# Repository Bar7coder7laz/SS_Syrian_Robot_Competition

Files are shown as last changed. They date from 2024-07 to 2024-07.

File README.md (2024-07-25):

Scud Storm Team Report for WRO Future Engineers Category (2024)
====
This repository represents the Scud Storm team's work for the WRO Future Engineers Category competition in 2024. It includes all the necessary documentation, code, models, and other materials used in the design, construction, and programming of our self-driving robot. Our focus has been on creating a robust and efficient vehicle capable of navigating a track with obstacles, adhering to competition rules, and demonstrating advanced engineering skills.

**Important Note:** If the GitHub repository is accessed from a restricted area, a VPN must be used for the repo to look good and display all content properly.

# Content

* `t-photos` contains 2 photos of the team (an official one and one funny photo with all team members)
* `v-photos` contains 6 photos of the vehicle (from every side, from top and bottom)
* `video` contains the video.md file with the link to a video where driving demonstration exists
* `schemes` contains one pdf for all the electromechanical components illustrating all the elements (electronic components and motors) used in the vehicle and how they connect to each other.
* `src` contains code of control software for all components which were programmed to participate in the competition
* `models` contains all the files used by 3D printers, laser cutting machines and CNC machines to produce the vehicle elements.
* `other` contains images thar used in this repository.

# Robot Mechanism

In self-driving cars, the most important aspect is their mechanical mechanisms, which ensure smooth and safe operation. Our design incorporates differential gears for the Rear-Wheel Drive (RWD) system, providing balance and control during turns. For steering, we utilize a Direct-Acting Steering mechanism, which offers precise control and reliability.

## Differential Gears

Differential gears play a crucial role in automotive engineering. They allow the wheels on a vehicle to rotate at different speeds, particularly when the car is turning. This functionality is vital because the inner wheels travel a shorter distance than the outer wheels during a turn.

### Types of Differentials

1. **Open Differential**: is the most common type, found in many non-performance vehicles. It is simple and cost-effective but can transfer torque to a wheel without traction, causing it to spin uselessly.

   <p align="center">
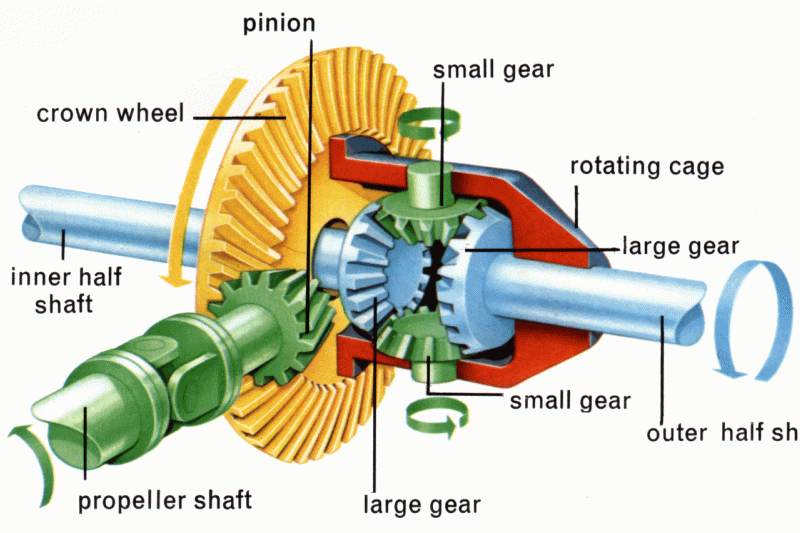
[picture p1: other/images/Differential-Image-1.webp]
     
   </p>

2. **Locking Differential**: Often used in off-road vehicles, this type can lock the wheels to spin at the same speed, providing better traction on uneven surfaces.

   <p align="center">
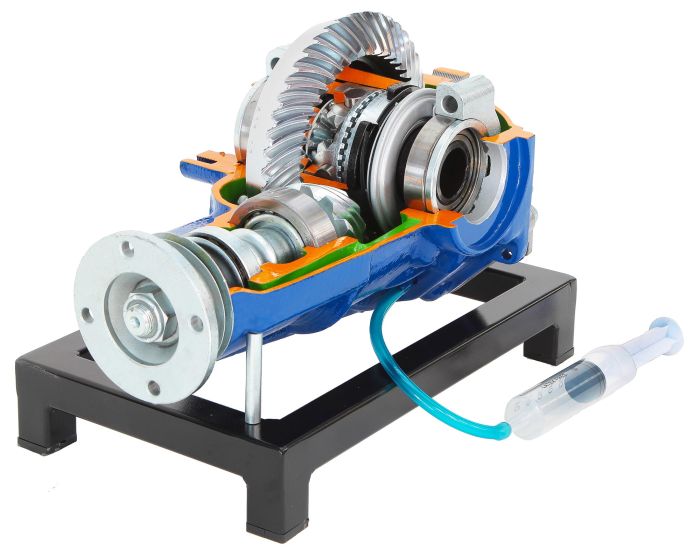
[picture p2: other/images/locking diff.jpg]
     
   </p>

3. **Limited-Slip Differential (LSD)**: Combines features of both open and locking differentials, allowing wheels to spin at different speeds but can transfer more torque to the wheel with better traction.

   <p align="center">
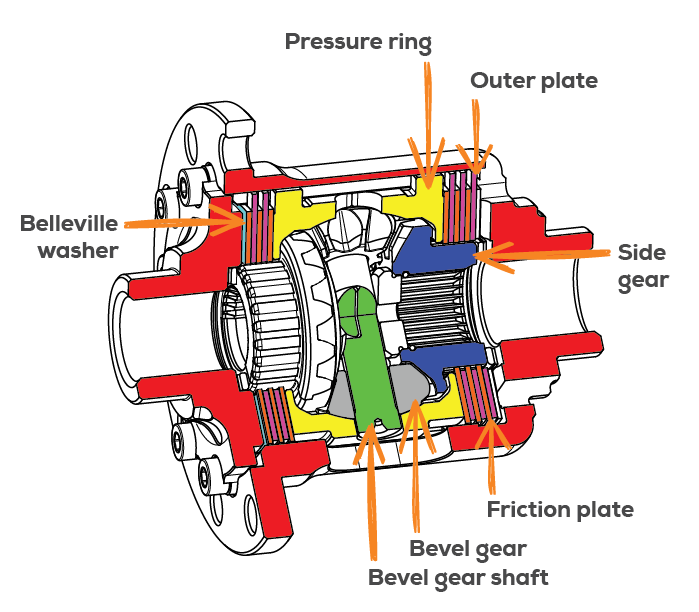
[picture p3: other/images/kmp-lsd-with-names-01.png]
     
   </p>

### Benefits of Differential Gears

- **Improved Handling**: Differentials enhance vehicle handling, especially around corners, by allowing wheels to rotate at appropriate speeds.
- **Increased Traction**: Locking and limited-slip differentials provide better traction on slippery or uneven surfaces.
- **Enhanced Stability**: They improve stability by distributing power evenly to the wheels, preventing loss of control.

## Direct-Acting Steering

Direct-Acting Steering mechanisms provide precise and responsive control, essential for the safety and efficiency of self-driving cars. This system translates the driver's or automated system's input directly into wheel movement without the delay and complexity of traditional steering systems.

### Advantages of Direct-Acting Steering

- **Enhanced Precision**: Direct control over the wheels' movement allows for more accurate and reliable steering.
- **Increased Safety**: By reducing the potential for mechanical failure, direct-acting systems improve the vehicle's overall safety.
- **Better Responsiveness**: The immediate translation of steering input to wheel action ensures a quicker response to driving conditions.

## Fusion Between Differential Gears and Direct-acting Steering Mechanisms in Our Robot

### Differential Gears Using Lego Parts
In our robot, we used differential gears, as shown in the following photo:

<p align="center">
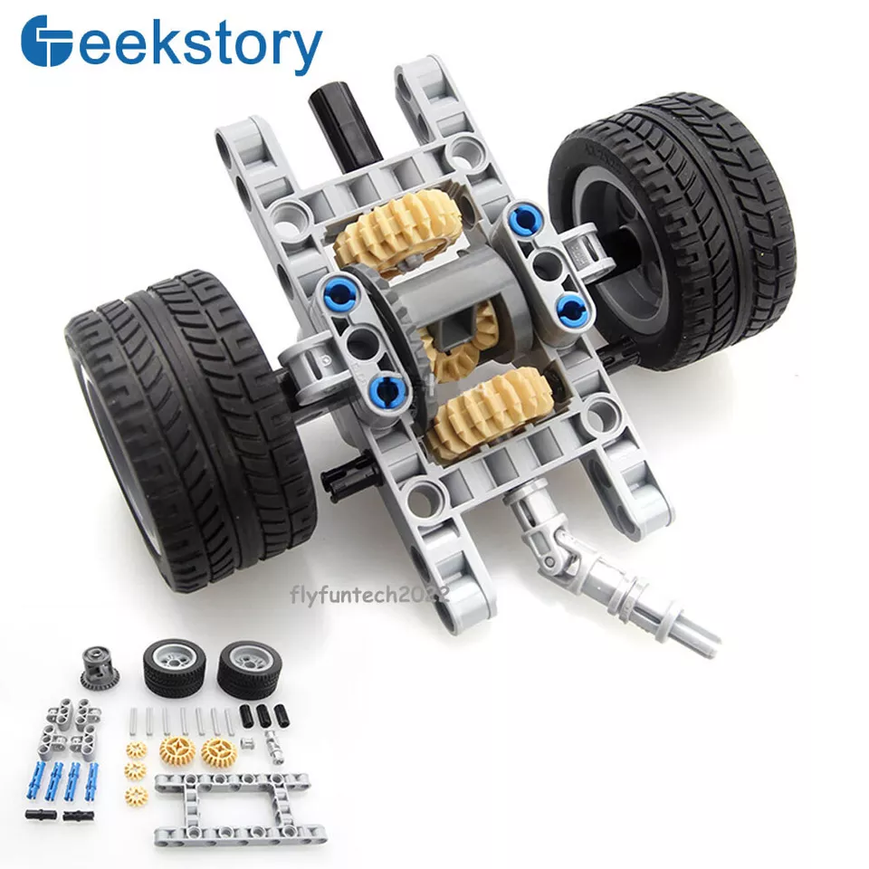
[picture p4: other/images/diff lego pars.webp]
  
</p>

### Direct-Acting Steering depending on Picar-X Kit
The steps of assembling the steering mechanism are shown below step-by-step:

<p align="center">
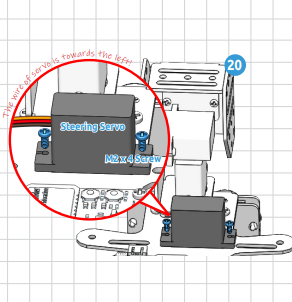
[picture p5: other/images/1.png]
  
</p>

<p align="center">
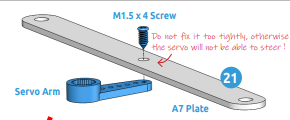
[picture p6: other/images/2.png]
  
</p>

<p align="center">
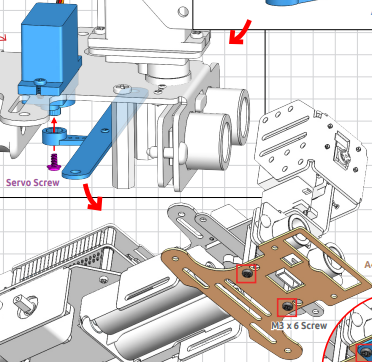
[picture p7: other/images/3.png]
  
</p>

<p align="center">
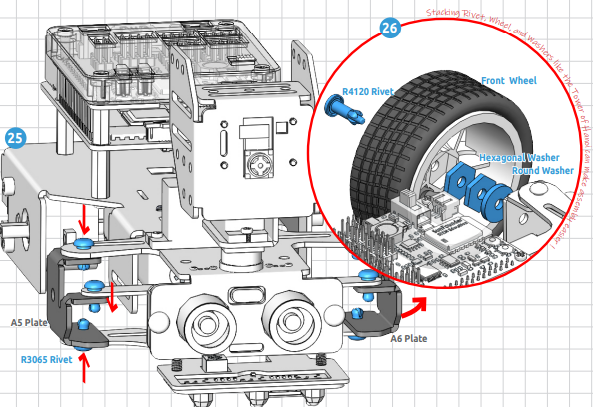
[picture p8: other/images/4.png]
  
</p>

Incorporating differential gears and direct-acting steering mechanisms in self-driving cars is essential for ensuring smooth turns, improved traction, precise control, and overall vehicle stability. Understanding these components helps us appreciate the technology that contributes to safer and more efficient driving experiences.

## Vehicle Main Body

The vehicle's main body is based on the Picar-x kit. The building instructions are available via the [link](https://github.com/sunfounder/sf-pdf/raw/master/assembly_file/a0000710-picar-x.pdf) with some vital modifications and crucial restructuring in order to be able to meet the competition requirements:

The robot Rear Wheel Drive (RWD) is the most important factor in any car whether it is a real car or a self-driving car. The Picar-x kit had two DC motors each one is responsible for one wheel. However, we are required to use one DC so we crafted a new design for the RWD. In this design, the transmission of motion is achieved through the implementation of differential gears using LEGO parts. The Importance of Differential Gears lies in that it enables the rear wheels to spin simultaneously at various speeds while preserving power distribution. When the robot is turning or there is a discrepancy in traction between the two wheels, the differential gear's main job is to allow the wheels on the same axle to rotate at different rates. It permits the wheels to spin at different speeds while distributing torque from the DC Motor to them. In order for the rear wheels to be compatible with the Lego differential gears, they were also replaced with Lego wheels. It's crucial to note that we utilized the identical Direct Acting Steering mechanism as the kit described above; but, because of their low friction characteristic, the front wheels had to be replaced due to the fact that the robot needs more force to steer at the right value.

Due to space constraints, we also added two extra plexi plates to the primary chassis of the robot( the primary chassis can only hold a place for the LiPo battery that we have). The first plexi was required for eight ultrasonic sensors (three on each side, one in front, and one in the back, and one in the middle with a drift angle of 35 degrees),  and a place for our main microcontroller is Atmega which is mounted on Arduino Mega 2560 board.Moreover, this plexi also contains a small fan for the RaspberryPi 4B, and a BTS7960 to control the DC motor. The RaspberryPi 4B, our robot's primary microprocessor, is located in the second plexi. On the other hand, the RaspberryPi is linked to a camera module that is located on two SG90 Servos, one of which moves it horizontally and the other vertically. Lastly, MPU_6050 is situated both above and in the middle of the robot with regard to the x and y axes. For more accurate measurements, we positioned the mpu precisely in the center of the robot using Lego parts.

### Picar-X Robot _VS_ Scud Storm Robot _(Our Robot)_ 
The following photos show a comparasion between our robot and the Picar-X Robot. This comparasion is to show how much effort did we put to the design to satisfy our algorithm requirments and the competition requirments:

<p align="center">
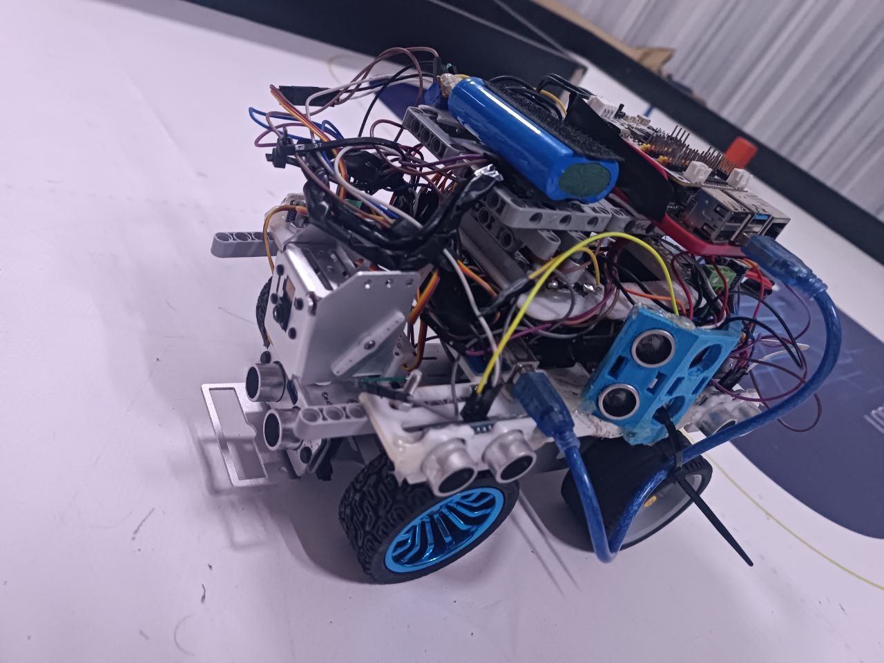
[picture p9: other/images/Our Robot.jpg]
Robot position before turn
  
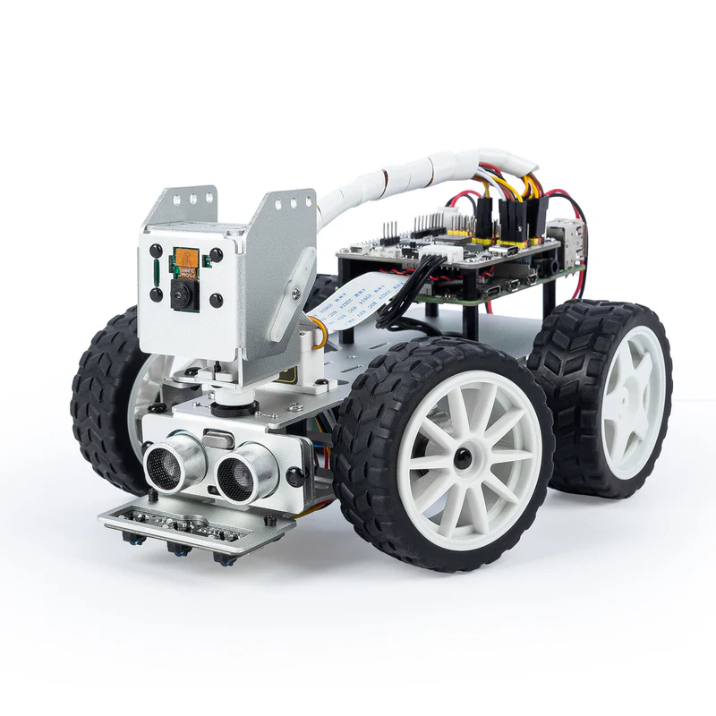
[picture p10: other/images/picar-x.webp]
  
</p>

## Mobility Management

### DC Motor

In general, the motors used in small self-driving cars are expected to possess several key attributes including light weight, compactness, and high efficiency. These characteristics are necessary to ensure that the motor can operate for extended periods of time while utilizing a limited power source. A motor that is relatively low-speed could be suitable for a small self-driving car as it can provide adequate torque to drive the vehicle while also being lightweight and compact. However, the selection of a motor for a self-driving car is influenced by a variety of factors such as the vehicle's size and weight, the desired speed and torque output, and the power requirements of the electronic components. Other considerations include the availability and cost of replacement parts as well as the level of expertise needed for installation and maintenance. After taking into account all of these factors the DC JGA25- 245 RPM motor was chosen because it met the desired specifications. It provides the following features: 

| Speed (r/min) | Current (Amp) | Torque (Kg.cm) | Power (Watt) |
|---|---|---|---|
| 133 | 0.5 | 0.75 | 1.1 |
| 245 | 0.65 | 1.4 | 2.4 |

### Motor Control Setup

To control the DC motor we used BTS 7960 driver circuit and the Arduino Mega board. Then we followed these steps:

1. We connected the BTS 7960 driver to the Arduino Mega. The BTS 7960 driver has six input pins which are used to control the motor. However, we only needed 4 pins to control our motor reliably. These pins are connected to the appropriate pins on the Arduino Mega. The connections are:
   - L_EN and R_EN pins are connected to digital output pins on the Arduino Mega.
   - L_PWM and R_PWM are connected to PWM output pin on the Arduino Mega.
2. Then we connected the DC motor to the BTS 7960 driver: The DC motor is connected to the output terminals of the BTS 7960 driver. The polarity of these connections determines the direction of the motor rotation.
3. Lastly, we connected the driver to an external 12V power supply.

### Servo Motor

Our choice of a SG90 Micro Digital 9G Servo (SunFounder Servo) motor for a small self-driving car depended on several factors which are presented below:

- **Compact size:** The SunFounder Servo motor is a small and lightweight motor (10± 0.5g) which makes it ideal for use in small self-driving cars where space is limited.
- **High torque:** Despite its small size, the SunFounder Servo motor can provide a relatively Stall Torque (1.4 kg/cm (4.8V) 1.6 kg/cm (6V)) which is essential for steering the car accurately and precisely.
- **Wide operating range:** The SunFounder Servo motor has a wide operating range of 0-180 degrees with a mechanical limit angle is 360 degrees which makes it versatile and suitable for a variety of steering applications.
- **Low power consumption:** The motor has a relatively low power consumption as follows:
  - Standby Current: ≤4 mA
  - Consumption Current (at 4.8V No Load): ≦50mA
  - Consumption Current (at 6 V no load): ≦60mA
  - Stall Current (at locked 4.8V): ≦550mA
  - Stall Current (at locked 6V): ≦650mA
- **High speed:** The motor has a suitable speed for the steering task (No Load Speed: 4.8V ≦0.14sec/60°; 6V ≦0.12sec/60°).

## Robot Design

Designing a robot for the Future Engineers WRO competition requires careful planning and consideration of several factors. For that we followed the following steps:

### Understanding the Competition Requirements

The first step is to thoroughly read and understand the competition rules and requirements. This helped us determine the specific tasks that the robot needs to perform and the constraints that need to be considered such as the weight and the dimensions of the robot.

### Defining the Robot's Objectives

Based on the competition requirements we determined the objectives of the robot such as the tasks it needs to perform the environment it will operate in and the constraints it needs to adhere to.

### Designing the Robot's Mechanical System
#### RWD Mechannism

It was previousely explained in details in this repository.

#### Steering Mechanism

Once the objectives are defined design the mechanical system of the robot including the wheels motors and any other mechanical components needed to achieve the objectives. As a steering mechanism, we chose the Direct-Acting steering mechanism which is a popular choice for small self-driving cars because it provides accurate and precise control over steering while also being relatively simple to implement. This mechanism uses a linkage system to allow the front wheels to turn at the same angles which is better when dealing with small self-driving cars than Ackermann steering for example. This design allows the car to have a small turning radius which is important for navigating tight spaces and making sharp turns. Additionally, it provides a stable and predictable steering response which is crucial for self-driving cars that need to maintain precise control over their movements.

### Choosing the Electronic Components

The selection process for the electronic components that will govern the robot's movements and behaviors has been conducted meticulously. These components include the microcontroller- an Arduino Mega board, and the microprocessor- a RaspberryPi 4B. Sensory devices have also been chosen encompassing Ultrasonic sensors, mpu6050 (gyroscope and acceleration sensor), and a RaspberryPi Camera 1.3 module (5 MegaPixels) which will provide the robot with the ability to perceive its environment. Actuators including a DC Motor and a Servo Motor have been chosen to facilitate the physical actions of the robot. The power supply will be ensured by one Li-poly RC 12 V and two 18650 li-ion (3.7 V) batteries. Additional electrical components such as the driver circuit and two step down voltage regulators (Lm2596) have also been selected to augment the robot's functionality. These components collectively will provide the necessary control over the robot's movements and actions.

## Power and Sense Management

### Power Supply

In our design, we utilized two 18650 li-ion (3.7 V) batteries to provide power for the RaspberryPi (since we have serial communication, RaspberryPi supplies Arduino). Additionally, the Li-poly RC 12 V is responsible to power all the other electronic components.

### Sensors

In addition to using a gyroscope, acceleration sensors (mpu 6050), and a camera to detect pillars, we integrated eight ultrasonic sensors (HC-SR04), three of which were placed on each side of the robot, one on the front side, and one on the left back side. Two of the sensors on each side have a unique feature in that two of them are parallel to the walls, but the middle one has a drifting angle of 35 degrees, a number that was carefully studied because it adds a great deal of flexibility to the obstacles management algorithm.

## Open Challenge Strategy

### Ultrasonic Sensors Reading

We created a newping array that contains all the sensors. It contains each sensor's trigger pin echo pin and max distance to ping. We also used a function that calculates the distance measured by an ultrasonic sensor with a specific id. The function uses a median filter to obtain a more accurate and stable distance measurement.

### Keeping the Robot Straight in the First Straightforward Section

We used a PD controlling algorithm that depends on the value of the tilt angle measured by the gyroscope sensor to calculate the corrected angle. This algorithm controls the robot in a way that makes the tilt angle measured by the gyroscope equal to a reference angle. And any deviating from this reference will be considered an error and will be corrected by the algorithm. We used this algorithm to control the robot movement in the first straightforward section before identifying the movement direction. The algorithm works as follows:

#### Identifying the Reference Angle

The reference angle is the angle measured by the gyroscope at the beginning of the round. It is important to consider that the robot may not be completely straight at the beginning of the round so the reference angle is corrected by subtracting the tilt angle of the robot that is calculated depending on ultrasonic sensors’ readings.

#### Calculating Angle Error

The angle error is the difference between the angle measured by the gyroscope during the movement and the reference angle.

<p align="center">
  
</p>

#### Calculating the PD Output

<p align="center">
  
</p>

Where:
- out is the output correction of the algorithm.
- angError_t is the angle error calculated at the time t.
- angError_{t-1} is the angle error calculated at the time t-1.
- timeDifference is the time difference between the two readings of the angle.
- k_p is the proportional constant.
- k_d is the differential constant.

#### Calculating the Corrected Angle

The corrected angle is the angle that would be set to the servo motor to correct the robot movement. It is calculated with the following formula:

<p align="center">
  
</p>

Where:
- servoAng is the angle that would be set to the servo motor to keep the robot straight.

### Detecting the First Turn and the Direction of Movement

If one of the left ultrasonics detects a distance greater than a specific threshold, then the direction of movement is counterclockwise. On the other hand, if one of the right ultrasonics detects a distance greater than the threshold, the direction of movement is clockwise. To make the code more dynamic we created two arrays called arr1 and arr2. Arr1 stores the IDs of the ultrasonic sensors that would be used to detect the wall, whereas arr2 stores the IDs of the ultrasonic sensors that would be used to detect a turn. The values of these two arrays are identified in the first turn.

### Keeping the Robot Straight After Identifying the Direction of Movement

After identifying the direction of movement the robot will be kept straight depending on wall detection algorithm that detects the outer wall. This algorithm controls the robot in a way that minimizes the tilt angle of the robot that is calculated using ultrasonic sensors’ readings. It calculates the tilt angle of the robot and multiplies it by a constant to obtain the corrected angle that would be set to servo motor. The value of this constant is obtained from experiment and calibration. The algorithm works as follows:

#### Calculating the Tilt Angle of the Robot

This angle is calculated depending on the readings of the two left or two right ultrasonic sensors as follows:

<p align="center">
  
</p>

Where:
- dis1 is the distance measured by the front left or front right ultrasonic sensor.
- dis2 is the distance measured by the back left or back right ultrasonic sensor.
- UltraDis is the distance between the front left and the back left sensors which is the same as the distance between the front right and the back right sensors.

#### Calculating the Corrected Angle

The corrected angle is the angle that would be set to the servo motor to correct the robot movement and is calculated as follows:

<p align="center">
  
</p>

Where:
- correctedAng is the angle that would be set to servo motor to correct the robot movement.
- StraightAng is the servo angle that keeps the robot straight.
- Sign is a variable that indicates the direction of movement. It is equal to 1 if the direction is CW, whereas it is equal to -1 if the direction is CCW.
- k_p is a constant identified by experiment and calibration.
- tiltAng is the tilt angle of the robot.

### Detecting Turns

A turn is detected if one of the ultrasonic sensors whose IDs are stored in arr2 array measures a distance greater than a specific threshold.

### Turning the Robot

Once a turn is detected the robot would turn left or right depending on the identified movement direction. The turn angle is calculated depending on the tilt angle of the robot before the turn. After the turn angle is calculated the robot would turn until the difference between the current gyro angle and the reference gyro angle would be equal to turn angle. The turn angle is calculated as following:

<p align="center">
  
</p>

<p align="center">
  
</p>

Where: 
- turnLeftAng is the required change in gyro angle to complete the left turn.
- turnRightAng is the required change in gyro angle to complete the right turn.
- tiltAng is the tilt angle of the robot from the wall which is calculated with formula (4).
- requiredLeftAng is the required change in gyro angle to complete the left turn in case the tilt angle of the robot before the turn is zero.
- requiredRightAng is the required change in gyro angle to complete the right turn in case the tilt angle of the robot before the turn is zero.

### Stopping the Robot in the Finish Section

After completing three laps the robot must stop in the finish section. To do this we used a counter that counts the number of turn times. The value of this counter is increased after completing each turn. When its value is equal to 12 the three laps will be completed. The finish section is recognized depending on the value of the front ultrasonic sensor. The robot would stop when the value of the front distance is less than a specific threshold.

# Obstacle Challenge Algorithm

In the obstacle challenge, the vehicle must complete three (3) laps on the track with randomly placed green and red traffic signs. The traffic signs indicate the side of the lane the vehicle must follow. The traffic sign to keep to the right side of the lane is a red pillar. The traffic sign to keep to the left side of the lane is a green pillar. The continuation of the vehicle to the third round is indicated by the last traffic sign of the second round. A green traffic sign indicates that the robot must go ahead and continue the third round in the same direction. A red traffic sign indicates that the vehicle must turn around and complete the third round in the opposite direction. The vehicle should not move any of the traffic signs. After the robot completes the three rounds, it has to find the parking lot and perform parallel parking.

In our algorithm, there are two ways to pass the pillars depending on the pillars' and the robot's positions.

## Passing Pillars that are at the End of the Section

At the beginning of the round, the camera will take a photo to determine whether there is a pillar at the end of the straightforward section and what its color is. When the pillars are at the end of the straightforward section, the robot may be at the beginning or in the middle of this section. In this case, the robot may move forward immediately to pass the pillar or it needs to turn before. This depends on the robot's position and the pillar’s color.

- If the robot is close to the left wall and the pillar is green or the robot is close to the right wall and the pillar is red, the robot can move immediately to pass the pillar without turning. The distance from the wall that identifies whether the robot needs a turn or not is identified with testing and calibration.
- If the pillar is red and the robot is far from the right wall, the robot needs to turn right about 35 degrees, move forward until it is close to the right wall, then turn left to return straight. Then it can move forward to pass the pillar. The same movements will be done if the pillar is green and the robot is far from the left wall but with reversed turn directions.

To get an accurate turn angle, we used the middle left and the middle right ultrasonic sensors. If the robot needs to turn left to pass the green pillar: first, the values measured by the front left and back left sensors would be less than the value measured by the middle left one. Ending the turn would be appropriate when the value of the middle left distance is the least. Therefore, the robot will turn until the value of the middle-left sensor is the least. The following figures illustrate the robot's position before and after the turn:

<p align="center">
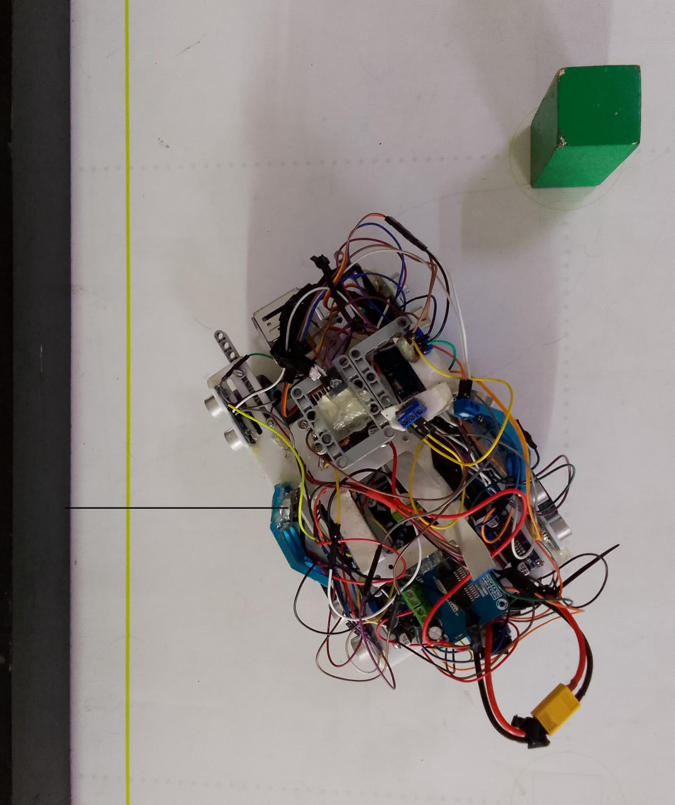
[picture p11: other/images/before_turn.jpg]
Robot position before turn
  
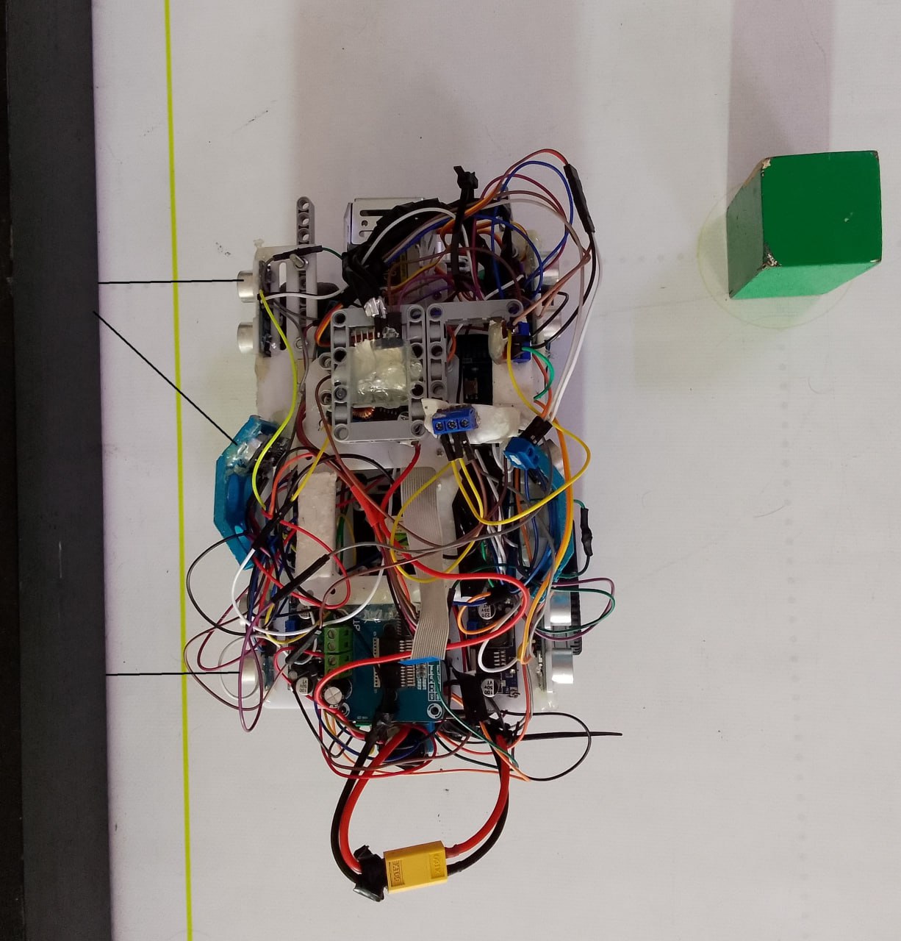
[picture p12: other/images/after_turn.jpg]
Robot position after turn
  
</p>

- After turning, the robot will move forward with the PID algorithm until the distance measured by the middle sensor is less than a specific threshold. This threshold is determined by calibration. Then the robot will turn left until the value read by the back-left sensor is less than the two other left sensors' values, making the robot straight. After that, the robot will move forward until it passes the pillar completely.
- Passing the red pillar is done similarly with reversed turn directions.

## Passing Pillars that are at the Beginning and in the Middle of the Section

After the robot passes the pillar that is at the end of the straightforward section, it will stop and move the camera’s servo to take photos and detect whether there are pillars at the beginning and the middle of the next straightforward section and what their colors are.

- If the detected pillar is red and the direction is counterclockwise or the detected pillar is green and the direction is clockwise, the robot will move forward with the PID algorithm until the front ultrasonic sensor measures a distance less than a specific threshold. Its value is determined by calibration. Then the robot will perform a 90-degree turn to the left or right depending on the direction of movement.
- If the detected pillar is green and the direction is counterclockwise or the detected pillar is red and the direction is clockwise, the robot will move backward with the PID algorithm until the front ultrasonic sensor measures a distance greater than a specific threshold. Its value is determined by calibration. Then the robot will perform a 90-degree turn to the left or right depending on the direction of movement.

After the robot performs the turn, it will move forward with the PID algorithm until the back ultrasonic sensor measures a distance greater than a specific threshold. So the pillar would be passed. Then the robot will stop and take a photo to determine whether there is a pillar at the end of the straightforward section and what its color is. The same steps will be repeated to pass the pillars at the end of the section and then at the beginning and the middle of the next straightforward section.

## Parking Lot 

### Avoiding the Parking Lot

When the camera detects a parking lot (by detecting the magenta color), the robot adjusts its threshold for passing the red pillar (increasing the middle ultrasonic distance threshold) so that the robot keeps away from the outer wall. Passing the green pillar in the parking lot section will remain the same (as there is no parking lot).

### Parking in the Parking Lot

After completing the three official laps, the robot can avoid pillars in any desired direction regardless of the pillar's color (passing without moving the pillars), so the robot keeps moving forward near the inner wall and turning (in other words, the robot assumes that all the pillars become green in its search for the parking lot). When the robot detects the parking lot after the three official laps, it keeps moving till the contour size of the magenta color becomes under a threshold (when the parking wall becomes close) and the back left or back right ultrasonic sensors (depending on the movement direction) detects a close object (closer than the outer wall), the robot turns 90 degrees and enters the parking lot partially. 

**Note:** Due to the lack of time, we are still working on the parking lot so that we can achieve the full parking case.

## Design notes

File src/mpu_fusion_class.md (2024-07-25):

# `mpu_fusion` Class

## Overview

The `mpu_fusion` class interfaces with the MPU6050 sensor, utilizing its Digital Motion Processor (DMP) to provide accurate orientation data, specifically the yaw angle. The class handles the initialization, calibration, and reading of sensor data to give reliable yaw values.

## Algorithm Explanation

### Initialization

1. **I2C Setup:**
   - The class starts I2C communication and sets the clock speed to ensure fast data transfer. This setup is crucial for timely communication between the MPU6050 sensor and the microcontroller.

2. **MPU6050 Initialization:**
   - The MPU6050 sensor is initialized, and the DMP is set up. This involves configuring the sensor's internal registers to prepare it for data collection and processing.

3. **Set Offsets:**
   - Gyro and accelerometer offsets are configured. These offsets are determined during the calibration process to account for any sensor biases. Proper offsets ensure that the sensor provides accurate measurements.

4. **Calibration:**
   - The accelerometer and gyroscope are calibrated to eliminate any bias and ensure accurate readings. Calibration involves adjusting the sensor readings to match known reference values, which helps in reducing systematic errors.

5. **Enable DMP:**
   - If the DMP initialization is successful, it is enabled to start processing the sensor data. The DMP processes raw data from the accelerometer and gyroscope to provide refined orientation data.

6. **Retrieve Packet Size:**
   - The expected packet size for the DMP is retrieved for future data reads. This packet size indicates how much data will be sent in each DMP update, allowing for efficient data handling.

### Data Processing

1. **Check DMP Readiness:**
   - Before processing any data, the class checks if the DMP is ready. This ensures that the data being read is valid and reliable.

2. **Read DMP Packet:**
   - The class checks for a new DMP packet, which contains the processed sensor data. DMP packets encapsulate orientation data calculated from raw sensor inputs.

3. **Extract Quaternion:**
   - The quaternion representing the sensor’s orientation is extracted from the DMP packet. Quaternions are a mathematical representation that avoids the gimbal lock problem and provides smooth, continuous orientation tracking.

4. **Calculate Gravity Vector:**
   - Using the quaternion, the gravity vector is calculated. This step is crucial for distinguishing between linear acceleration (caused by movement) and gravitational acceleration (caused by tilt). The gravity vector helps in isolating the tilt component of the sensor data.

5. **Compute Yaw, Pitch, and Roll:**
   - The yaw, pitch, and roll angles are computed from the quaternion and gravity vector. These angles describe the orientation of the sensor in three-dimensional space. 
   - **Yaw:** Rotation around the vertical axis.
   - **Pitch:** Rotation around the lateral axis.
   - **Roll:** Rotation around the longitudinal axis.

6. **Store Yaw Angle:**
   - The yaw angle, representing the rotation around the vertical axis, is converted from radians to degrees for easier interpretation and stored in the provided variable. Converting to degrees makes the data more intuitive and useful for applications.

### Sensor Fusion

The MPU6050 uses sensor fusion algorithms within its DMP to combine data from the accelerometer and gyroscope. Here's how it works:

1. **Accelerometer Data:**
   - Measures linear acceleration in three axes (X, Y, Z). This data is used to determine the tilt of the sensor. However, accelerometer data can be noisy and is susceptible to linear motion.

2. **Gyroscope Data:**
   - Measures angular velocity in three axes. Gyroscopes provide good short-term accuracy but tend to drift over time.

3. **Complementary Filter:**
   - The DMP likely uses a complementary filter or a similar algorithm to combine accelerometer and gyroscope data. 
   - The accelerometer provides long-term stability, correcting the drift of the gyroscope.
   - The gyroscope provides short-term stability, smoothing out the accelerometer’s noise.

4. **Quaternion Calculation:**
   - The sensor fusion algorithm calculates quaternions from the combined data. Quaternions provide a robust way to represent rotations, avoiding issues like gimbal lock.

5. **Gravity Vector Calculation:**
   - The quaternion is used to compute the gravity vector. This helps in isolating the gravity component from the total acceleration, allowing for accurate orientation estimation.

6. **Angle Computation:**
   - Yaw, pitch, and roll angles are computed using the quaternion and gravity vector. These angles provide a comprehensive description of the sensor's orientation.

## Usage

The `mpu_fusion` class can be used in projects requiring accurate orientation data from the MPU6050 sensor, such as:

- Robotics
- Drones
- Motion tracking applications
- Virtual reality systems

## Example Usage

To use the `mpu_fusion` class, initialize it with the appropriate gyro offsets, call the `init()` method to set up the sensor, and use `get_Angle_Z()` to retrieve the yaw angle.

## Notes

- Ensure the MPU6050 sensor is properly connected to your Arduino board.
- The `mpu_fusion` class relies on the DMP firmware provided by InvenSense, which processes raw sensor data for more accurate orientation estimates.

## Conclusion

The `mpu_fusion` class provides a comprehensive solution for integrating the MPU6050 sensor into your projects, leveraging its DMP for accurate and reliable orientation data.

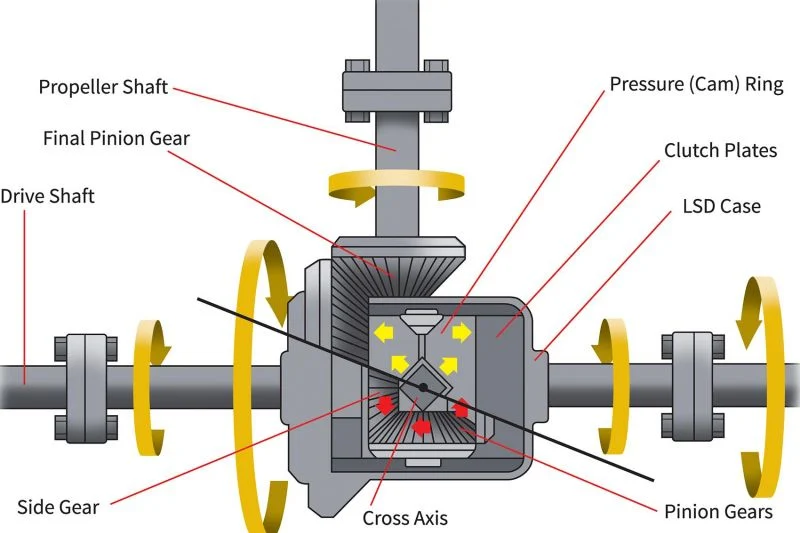
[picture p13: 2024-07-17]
other/images/Differentials-Image-2.webp

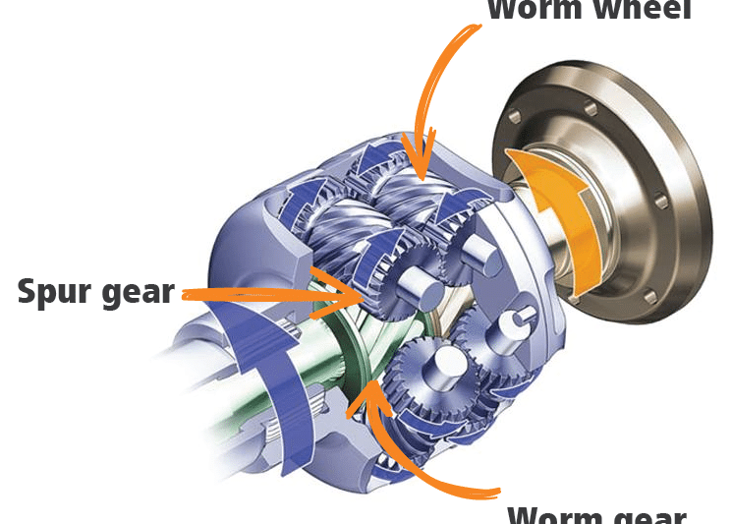
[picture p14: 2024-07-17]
other/images/Differentials-Image-4.webp

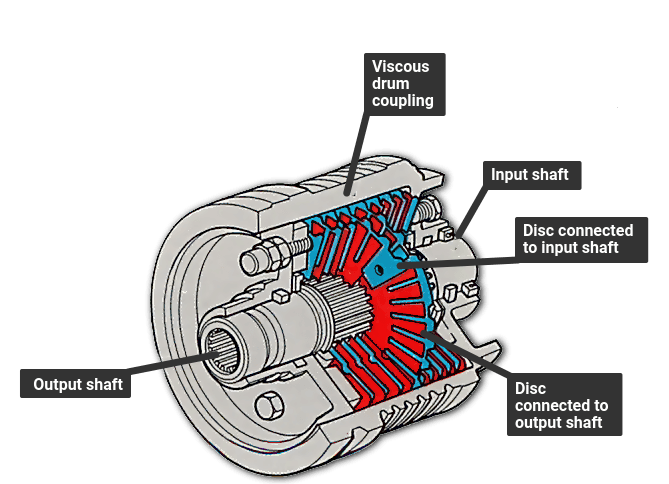
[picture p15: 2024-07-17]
other/images/Differentials-Image-3.webp

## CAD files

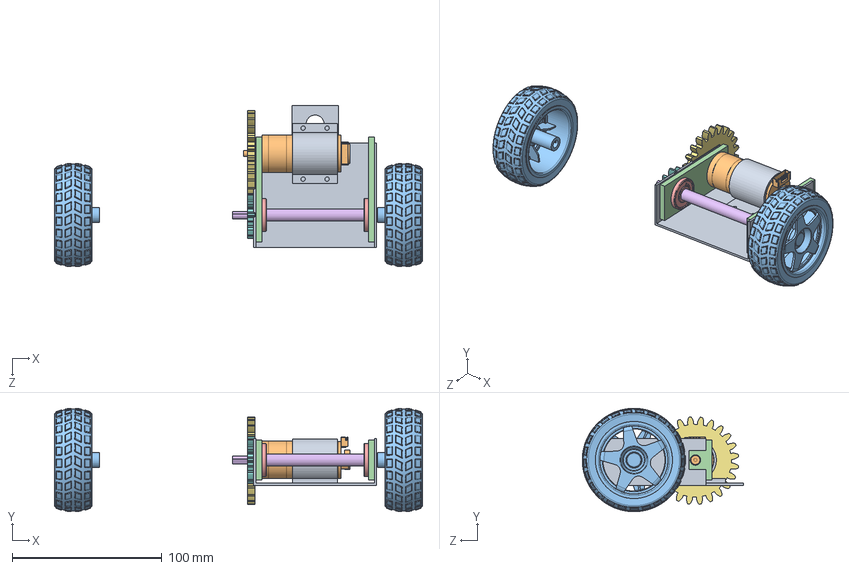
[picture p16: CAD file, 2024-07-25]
models/Assem1.SLDASM
245.5 x 68.9 x 107.7 mm
براء مسننات منارة
GM25-370
Wheel x 2
holder x 2
Rolman_8mm x 2
axsis
Big Gear 2
Small Gear 2
holder motor

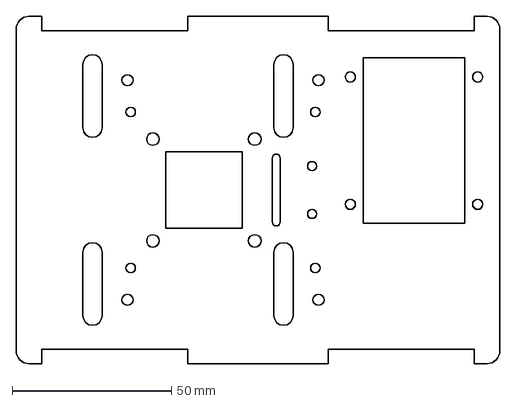
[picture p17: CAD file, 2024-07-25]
models/Hadi new plexi with bts and two ultras.DXF
152.0 x 109.0 mm

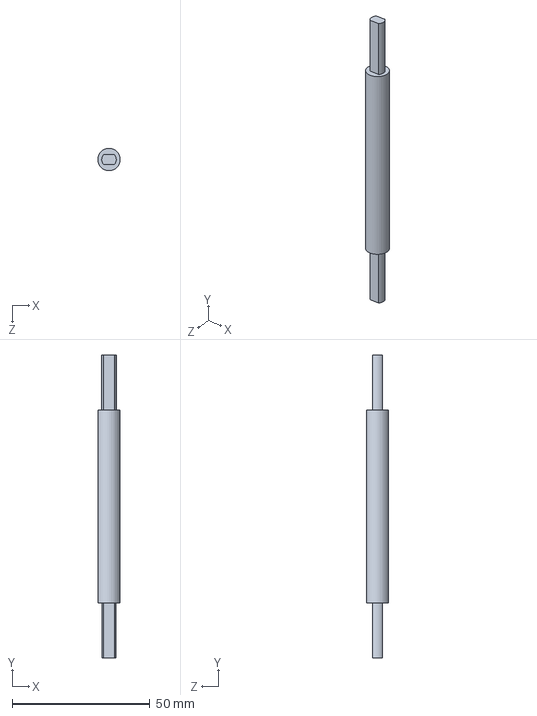
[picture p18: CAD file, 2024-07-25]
models/axsis.SLDPRT
8.15 x 110.0 x 8.15 mm

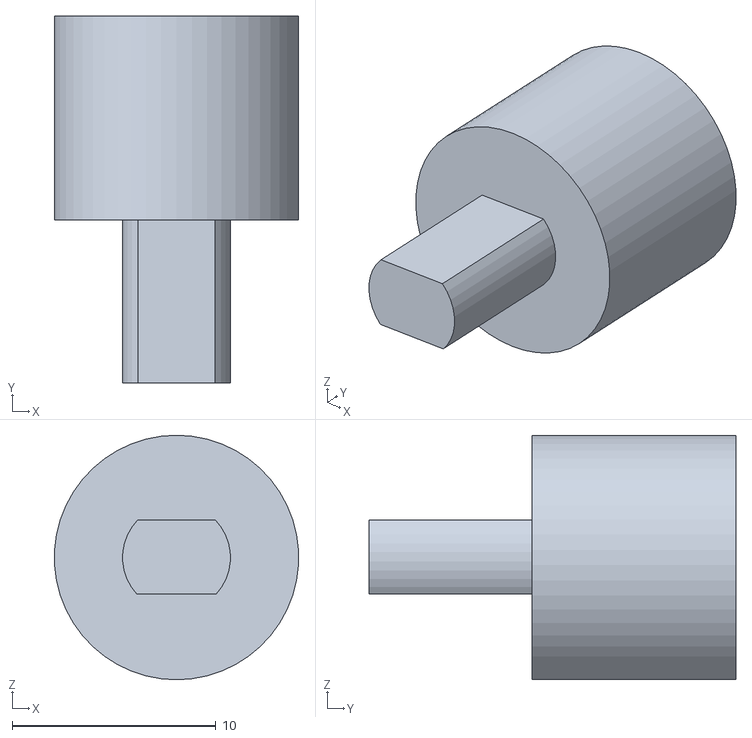
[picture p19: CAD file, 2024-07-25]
models/ON AXSIS1.STL
12.0 x 18.0 x 12.0

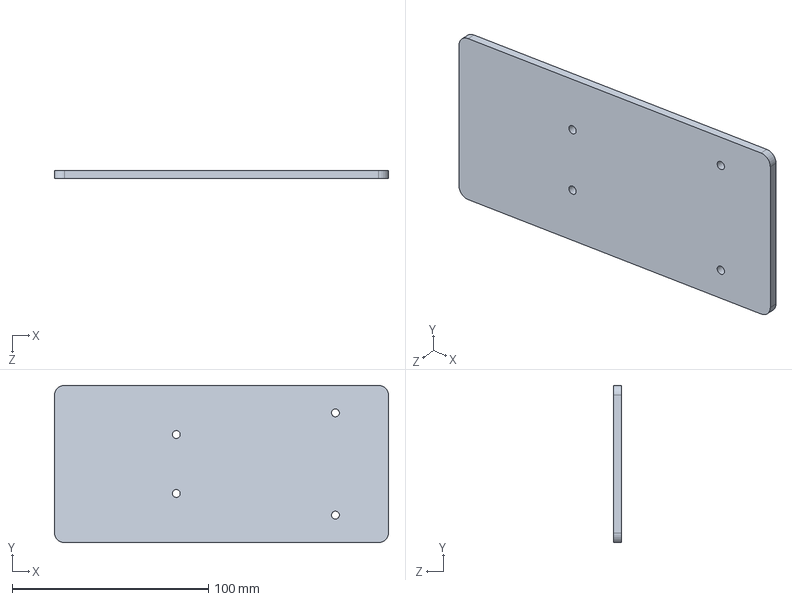
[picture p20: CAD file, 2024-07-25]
models/Part1.SLDPRT
170.0 x 80.0 x 4.00 mm

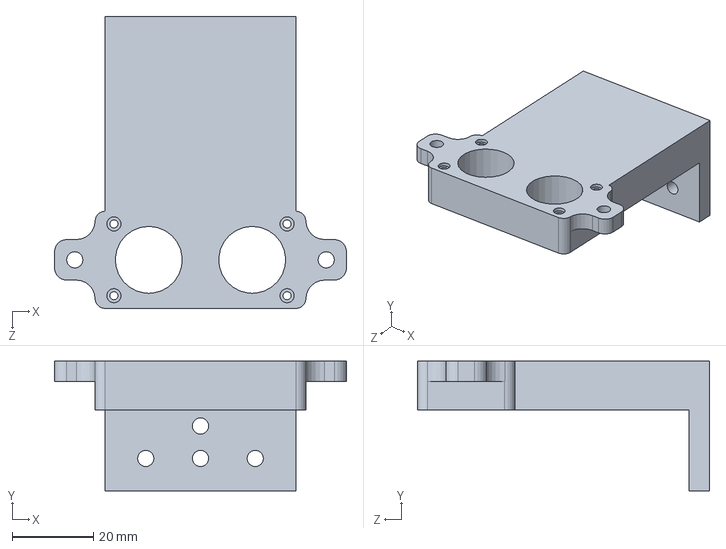
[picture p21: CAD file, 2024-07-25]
models/ultrasonic holder2.SLDPRT
72.0 x 32.0 x 72.0 mm

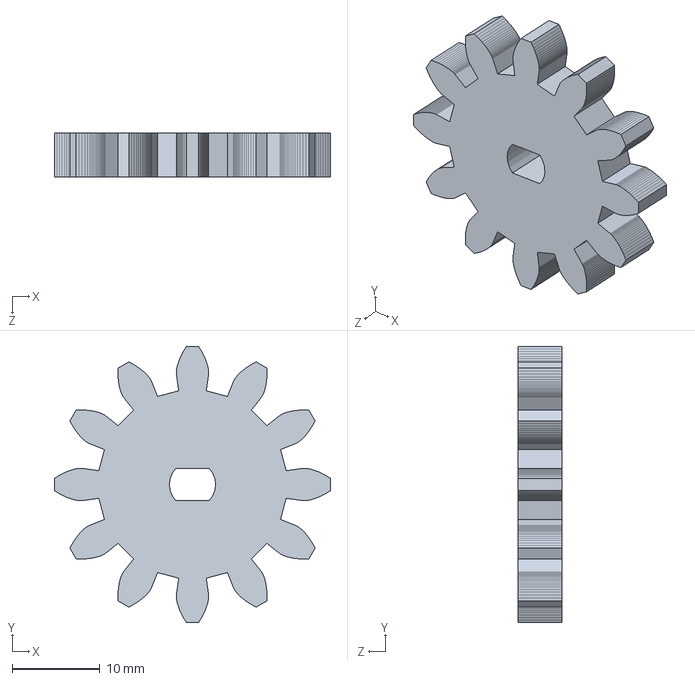
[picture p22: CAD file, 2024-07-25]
models/Small Gear 2.SLDPRT
31.5 x 31.5 x 5.00 mm

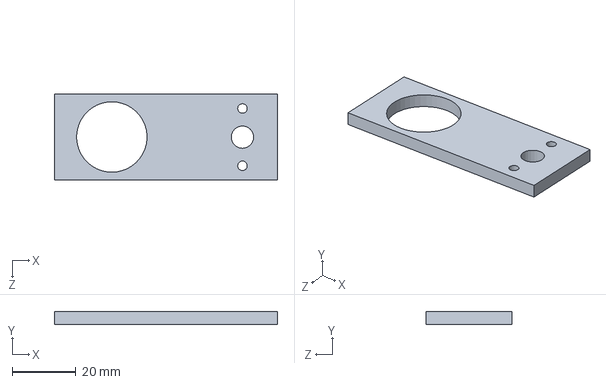
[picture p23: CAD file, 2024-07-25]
models/holder.SLDPRT
70.0 x 4.00 x 27.0 mm

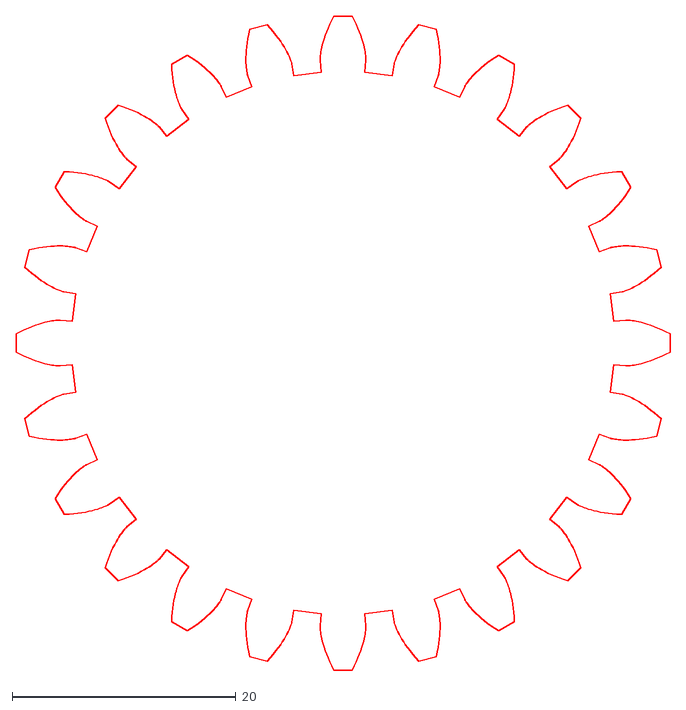
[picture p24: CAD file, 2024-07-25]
models/spur_gear_mod2.25_pa20_N24.dxf
58.5 x 58.5

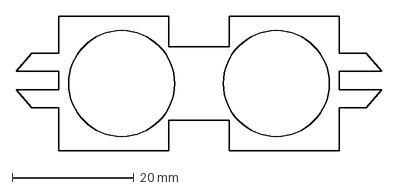
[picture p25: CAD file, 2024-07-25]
models/ultra plexi.DXF
60.0 x 22.0 mm

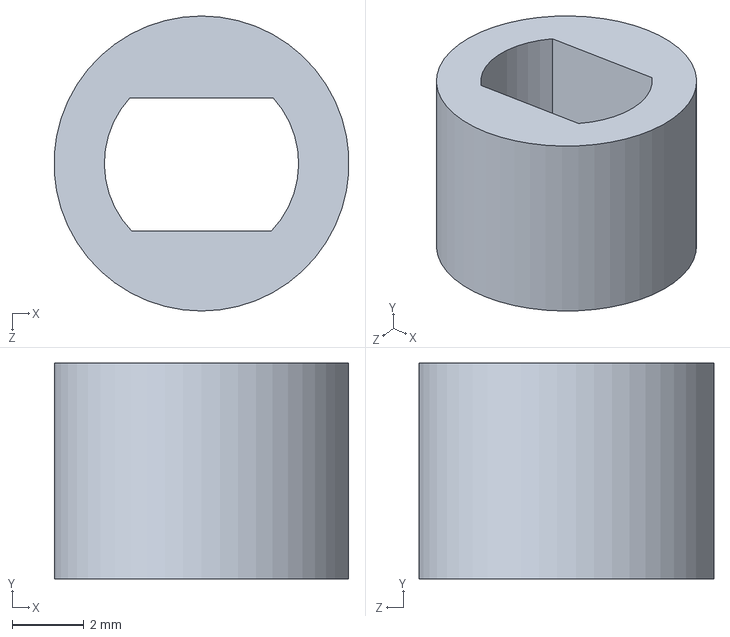
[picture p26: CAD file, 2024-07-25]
models/on rolman.SLDPRT
8.18 x 6.00 x 8.20 mm

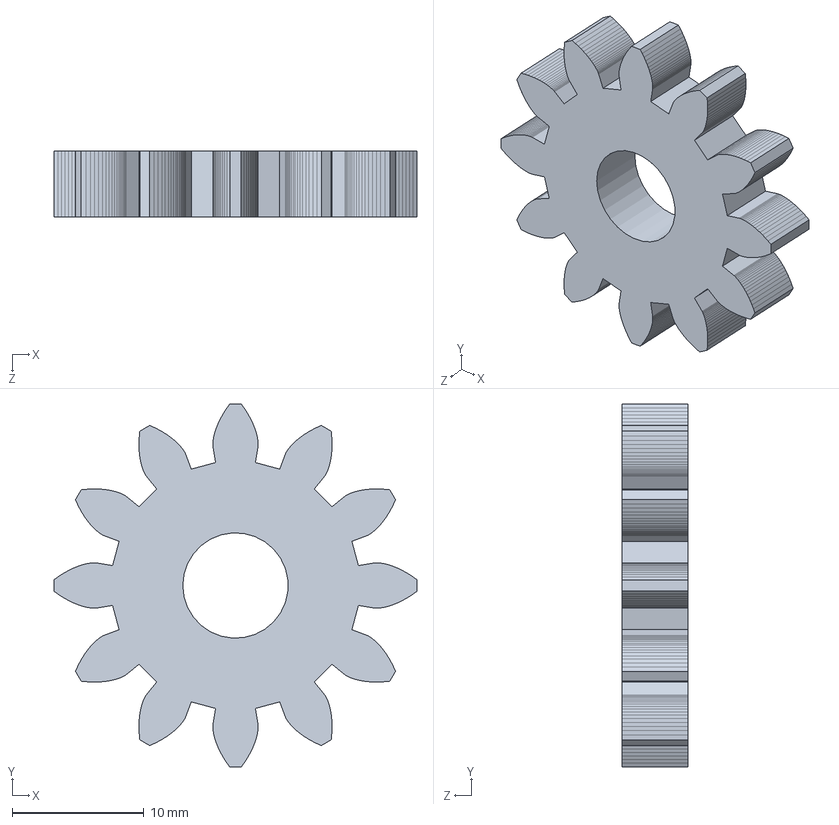
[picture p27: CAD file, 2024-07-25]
models/Small Gear.SLDPRT
27.6 x 27.6 x 5.00 mm

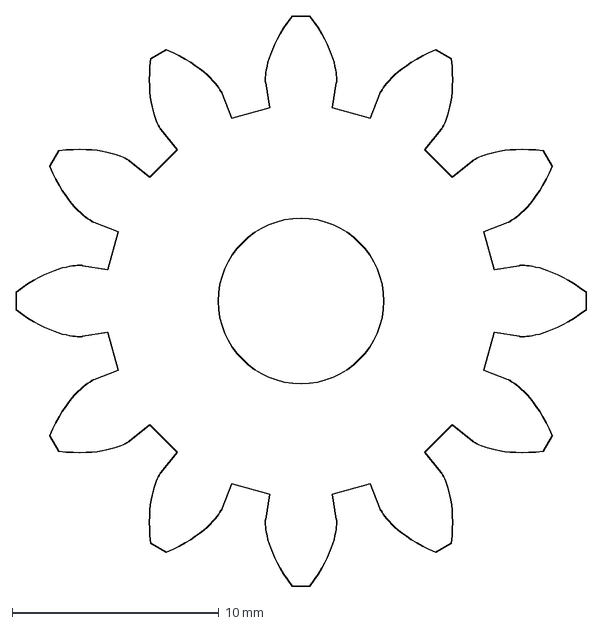
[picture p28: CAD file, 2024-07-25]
models/Small Gear new.DXF
27.6 x 27.6 mm

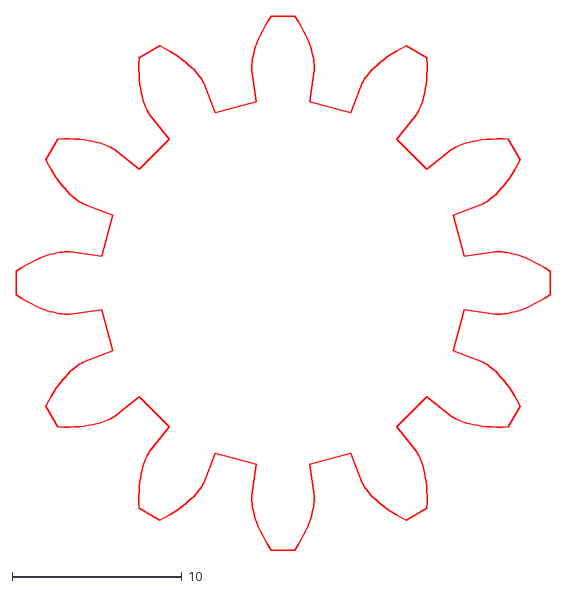
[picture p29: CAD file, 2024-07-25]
models/spur_gear_mod2.25_pa20_N12.dxf
31.5 x 31.5

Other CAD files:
models/ON AXSIS.SLDPRT
models/Big Gear.SLDPRT
models/Gears.SLDPRT
models/holder motor.SLDPRT
models/Big Gear 2.DXF
models/Big Gear 2.SLDPRT
models/Big Gear 2.STL
models/ON AXSIS.STL
models/Part1.DXF
models/Small Gear 2.DXF
models/Small Gear 2.STL
models/axsis.STL
models/holder motor.STL
models/holder.DXF
models/holder.STL
models/ultrasonic holder2.STL

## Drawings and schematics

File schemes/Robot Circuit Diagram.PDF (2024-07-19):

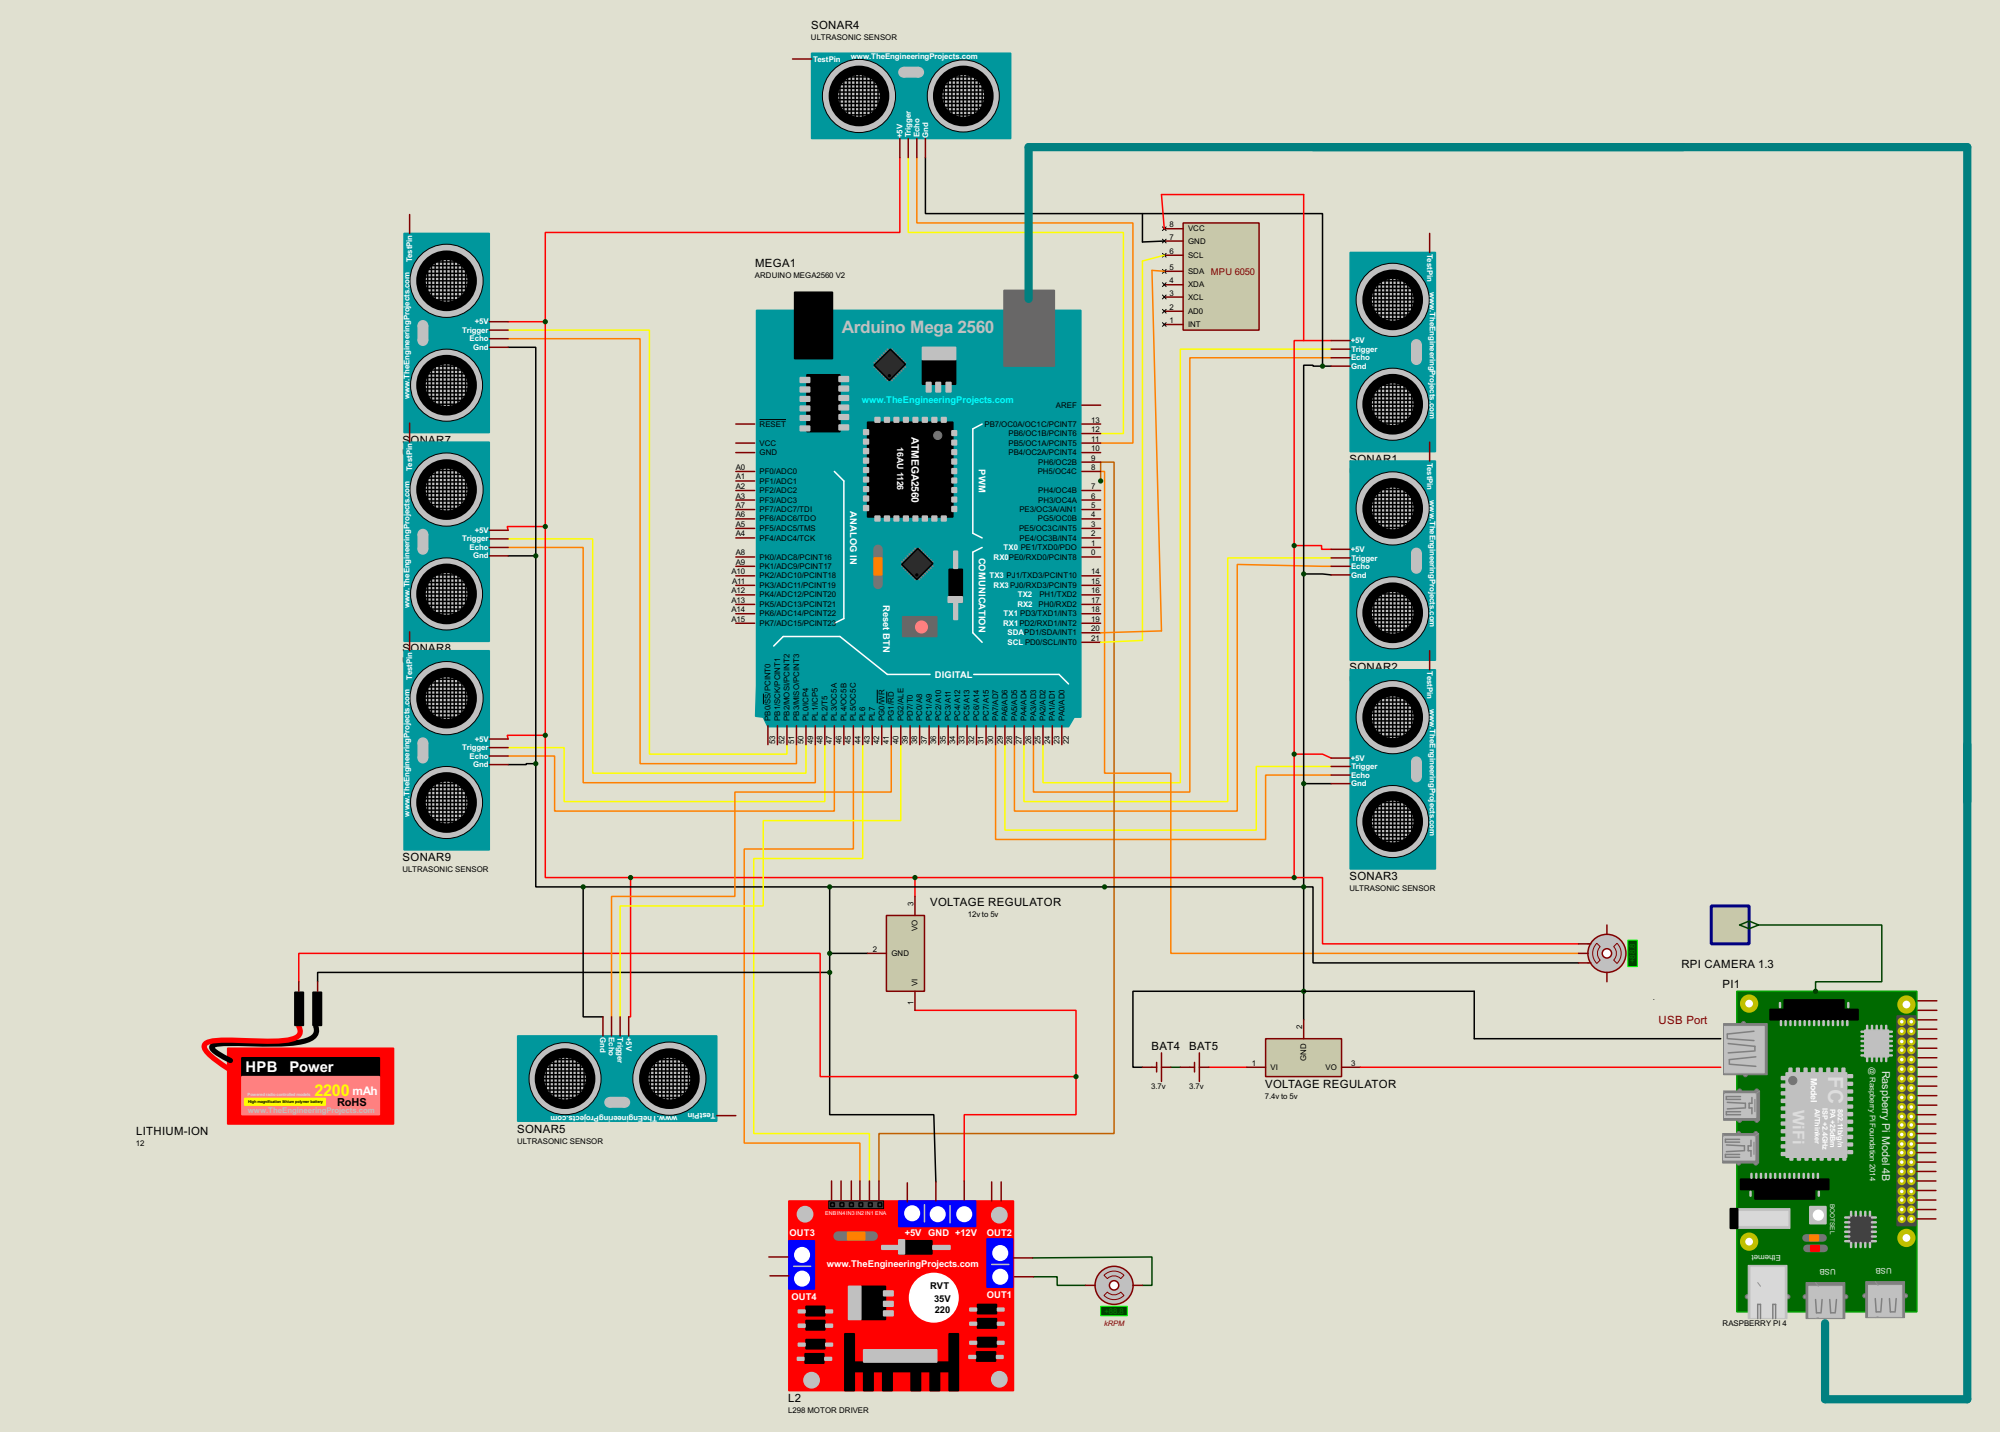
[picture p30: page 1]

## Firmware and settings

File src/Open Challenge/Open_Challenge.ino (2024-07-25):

#include <NewPing.h> // Library for ultrasonic sensor
#include <Servo.h> // Library for controlling servo motors
#include "Arduino.h" // Standard Arduino library
#include "I2Cdev.h" // Library for I2C communication
#include "MPU6050_6Axis_MotionApps20.h" // Library for MPU6050 sensor with DMP
#include "math.h" // Standard math library
#include "mpu_fusion.h" // Custom library for MPU fusion

///////////////////////////////////////////////////////////////////////////////////////////////////////////////
// Variable declarations
int counter = 0; // Counter for turns
float distance = 0, real_distance = 0; // Distance measurements
float angle = 0, Angle = 0; // Angle measurements
float highest_angle = 0.27; // Highest allowable angle
float jbes = 0; // Servo position adjustment
float currentTimePID = 0, lastTimePID = 0, errorPID = 0, referencePID = 0, outputPID = 0; // PID control variables
float theta = 0, theta_mpu = 0, ref_mpu = 0; // Angle variables for MPU
float angle_mean = 0; // Mean angle
int reference_counter = 5; // Counter for reference calculation
float turn_right_ang = 45; // Turn right angle
float Set_Servo = 1; // Servo set flag
float last_errorPID = 0, deltaTimePID = 0; // Last angle error and delta time
int sign = 1; // Sign for direction
float first_ref = 0; // First reference angle
int cnt = 0; // General counter
int arr_right[3] = {3, 4, 5}; // Array for right sensors
int arr_left[3] = {0, 1, 2}; // Array for left sensors
int arrl[2] = {0, 1}; // Another array for left sensors
int pid_spd = 140; // PID speed
int pid_spd_slow = 120; // Slow PID speed
int turn_spd = 110; // Turning speed
int drib_spd = 105; // Dribbling speed
int dribend_spd = 110; // Dribbling end speed
int spd_after_turn = 150; // Speed after turn
int spd_back = 105; // Backward speed
int pid_red_spd = 85; // Reduced PID speed
int pid_green_spd = 85; // Green PID speed

int ptl = 72; // Position left
int ptr = 75; // Position right

float kpl = 1.0; // PID proportional constant left
float kpr = 1.0; // PID proportional constant right
float kp = kpl; // PID proportional constant

double kpc = 3, kdc = 2.3; // PID constants for control
double kpb = 4.6, kdb = 3.8; // PID constants for back control
float max_ang = 120, min_ang = 13; // Max and min angles for servo
int pos_R = 78 , pos_L = 60; // Servo positions
int pos = pos_L; // Initial servo position

///////////////////////////////////////////////////////////////////////////////////////////////////////////
// Servo declarations
Servo myservo;
Servo myservo2;
Servo myservo3;

// Pin definitions
#define flt 24
#define fle 25

#define blt 52
#define ble 53

#define frt 26
#define fre 27

#define brt 42
#define bre 43

#define ft 22
#define fe 23

#define bt 30
#define be 31

#define mlt 44
#define mle 45

#define mrt 36
#define mre 37

#define MAX_DISTANCE 310 // Maximum distance for ultrasonic sensors
#define MAX_DISTANCE2 500 // Secondary maximum distance for ultrasonic sensors

// Arrays for sensor pins
int echo[8] = {ble, mle, fle, bre, mre, fre, fe, be};
int trig[8] = {blt, mlt, flt, brt, mrt, frt, ft, bt};

// Sensor indices
int bl = 0, ml = 1, fl = 2;
int br = 3, mr = 4, fr = 5;
int f = 6, b = 7;
int arr1[] = {0, 1, 2}; // Left sensors
int arr2[] = {3, 4, 5}; // Right sensors

float d[8]; // Distance array for sensors
float m = 0.0185; // Distance conversion factor

// Array of NewPing objects for ultrasonic sensors
NewPing ultra[8] = {
  NewPing(trig[0], echo[0], MAX_DISTANCE),
  NewPing(trig[1], echo[1], MAX_DISTANCE),
  NewPing(trig[2], echo[2], MAX_DISTANCE),
  NewPing(trig[3], echo[3], MAX_DISTANCE),
  NewPing(trig[4], echo[4], MAX_DISTANCE),
  NewPing(trig[5], echo[5], MAX_DISTANCE),
  NewPing(trig[6], echo[6], MAX_DISTANCE),
  NewPing(trig[7], echo[7], MAX_DISTANCE),
};

// Function to get distance from ultrasonic sensor
float dist(int id, int it) {
  d[id] = m * ultra[id].ping_median(it); // Convert ping time to distance
  if (d[id] == 0) d[id] = MAX_DISTANCE; // If no ping, set distance to max
  return d[id];
}

// Motor control pins
#define R_EN 11
#define L_EN 33
#define R_PWM 12
#define L_PWM 13

// Function to move forward with specified speed
void forward(int pwm) {
  digitalWrite(R_EN, HIGH);
  digitalWrite(L_EN, HIGH);
  analogWrite(R_PWM, 0);
  analogWrite(L_PWM, pwm);
}

// Function to stop the motors
void stopp() {
  digitalWrite(R_EN, HIGH);
  digitalWrite(L_EN, HIGH);
  analogWrite(R_PWM, 0);
  analogWrite(L_PWM, 0);
}

// Function to move backward with specified speed
void backward(int pwm = 0) {
  digitalWrite(R_EN, HIGH);
  digitalWrite(L_EN, HIGH);
  analogWrite(R_PWM, pwm);
  analogWrite(L_PWM, 0);
}

// MPU fusion object
mpu_fusion imu(mx, my);

// Function to get Z-axis angle (yaw) from MPU
void get_AngleZ() {
  imu.get_Angle_Z(yaw); // Get yaw value
  if (Wire.getWireTimeoutFlag()) { // Check for I2C timeout
    Wire.end();
    delay(2000);
    Wire.begin();
    delay(5000);
    Wire.clearWireTimeoutFlag();
  }
  delay(5); // Delay to avoid too frequent DMP requests
  delta_yaw = yaw - last_yaw; // Calculate delta yaw
  if (delta_yaw < 150 && delta_yaw > -150) { // Handle DMP value wrap-around
    real_value += delta_yaw;
    imu_overall_val = real_value;
  }
  last_yaw = yaw;
}

// Function to calculate angle based on direction
float Angle_cal(int dir) {
  if (dir == 1) {
    Angle = atan((dist(2, 3) - dist(0, 3)) / 15.9);
  } else {
    Angle = atan((dist(5, 3) - dist(3, 3)) / 15.9);
  }

  if (Angle > highest_angle) {
    Angle = highest_angle;
  }
  if (Angle < (-1) * highest_angle) {
    Angle = (-1) * highest_angle;
  }
  Angle = Angle * 180 / M_PI;
  return Angle;
}

// Function to calculate distance based on direction
float Distance(int dir) {
  float distance;
  if (dir == 1) {
    distance = (0.65 * dist(2, 3) + 0.35 * dist(0, 3));
  } else {
    distance = (0.65 * dist(5, 3) + 0.35 * dist(3, 3));
  }
  angle = Angle_cal(dir) * M_PI / 180;
  real_distance = distance * cos(angle);
  return real_distance;
}

// Proportional control function for left side
void P_L(float kp) {
  jbes = pos - sign * (kp * (Angle_cal(sign)));
  if (jbes < min_ang) jbes = min_ang;
  if (jbes > max_ang) jbes = max_ang;
  myservo3.write(jbes);
}

// PID control function for angle adjustment
void controlPIDAngle(double current_angle) {
  currentTimePID = (micros()) * (1e-3);
  deltaTimePID = currentTimePID - lastTimePID;
  lastTimePID = currentTimePID;
  errorPID = current_angle - referencePID;
  outputPID = pos - (kpc * errorPID + ((errorPID - last_errorPID) / deltaTimePID) * kdc);
  if (outputPID > max_ang) outputPID = max_ang;
  if (outputPID < min_ang) outputPID = min_ang;
  myservo3.write(outputPID);
  last_errorPID = errorPID;
}

// Backward PID control function for angle adjustment
void controlPIDBackAngle(double current_angle) {
  currentTimePID = (micros()) * (1e-3);
  deltaTimePID = currentTimePID - lastTimePID;
  lastTimePID = currentTimePID;
  errorPID = current_angle - referencePID;
  outputPID = pos + (kpb * errorPID + ((errorPID - last_errorPID) / deltaTimePID) * kdb);
  if (outputPID > max_ang) outputPID = max_ang;
  if (outputPID < min_ang) outputPID = min_ang;
  myservo3.write(outputPID);
  last_errorPID = errorPID;
}

// Function to take reference for angle calculation
void take_ref(int dir) {
  angle_mean = 0;
  while (reference_counter--) {
    angle_mean += Angle_cal(dir);
  }
  reference_counter = 5;
  get_AngleZ();
  referencePID = imu_overall_val;
  referencePID -= (dir * (angle_mean / reference_counter));
}

// Function to take reference from MPU
void take_ref_mpu() {
  float mpu_mean = 0;
  for (int i = 0; i < reference_counter; i++) {
    get_AngleZ();
    mpu_mean += imu_overall_val;
  }
  referencePID = mpu_mean / reference_counter;
}

// Function to adjust reference based on given angle
void take_ref_mpu_ang(int angg) {
  referencePID = referencePID + sign * angg;
}

// Function to parse sensor values and find minimum
double Parse_Val(int *y, int l, int iter = 3) {
  double minn = 1.0 * MAX_DISTANCE;
  int ii;
  for (int j = 0; j < l; j++) {
    int i = y[j];
    d[i] = dist(i, iter);
    if (d[i] < minn) {
      minn = d[i];
      ii = i;
    }
    delay(1);
  }
  return ii;
}

// Start function to initialize servo and take reference
void start() {
  if (Set_Servo) {
    myservo3.write(pos_L);
    Set_Servo = 0;
    take_ref(1);
  }
}

// Function to reverse sensor arrays if conditions met
void revultra() {
  if (dist(0, 3) > 100 || dist(2, 3) > 100) {
    for (int i = 0; i < 3; i++) {
      arr1[i] = i + 3;
      arr2[i] = i;
    }
    pos = pos_R;
    sign = -1;
    ptl = ptr;
    kp = kpl;
  }
}

// Turn function for robot
void turn() {
  while (true) {
    if (dist(6, 3) > 35) break;
    backward(spd_back);
    get_AngleZ();
    controlPIDBackAngle(imu_overall_val);
  }
  myservo3.write(pos);
  theta = ptl - Angle_cal(sign);
  get_AngleZ();
  theta_mpu = imu_overall_val;
  ref_mpu = theta_mpu;
  theta = ref_mpu + sign * theta;

  while (true) {
    if ((sign * (theta_mpu - theta)) >= 0) break;
    get_AngleZ();
    theta_mpu = imu_overall_val;
    forward(turn_spd);
    myservo3.write(pos + sign * turn_right_ang);
  }
  myservo3.write(pos);
  take_ref(sign);
  counter += 1;
  while (true) {
    if (dist(7, 3) > 100) break;
    forward(pid_spd);
    get_AngleZ();
    controlPIDAngle(imu_overall_val);
  }
}

// Arduino setup function
void setup() {
  imu.init();
  pinMode(R_EN, OUTPUT);
  pinMode(L_EN, OUTPUT);
  pinMode(R_PWM, OUTPUT);
  pinMode(L_PWM, OUTPUT);
  Serial.begin(9600);
  myservo2.attach(8);
  myservo2.write(70);
  myservo3.attach(7);
  myservo.attach(9);
  myservo.write(110);
}

// Arduino loop function
void loop() {
  if (!counter) {
    start();
    while (true) {
      if (dist(2, 3) > 100 || dist(0, 3) > 100 || dist(3, 3) > 100 || dist(5, 3) > 100) {
        stopp();
        break;
      }
      if (dist(6, 3) <= 100 && dist(6, 3) > 0) {
        forward(pid_spd_slow);
        get_AngleZ();
        controlPIDAngle(imu_overall_val);
      }
      if (dist(6, 3) > 100) {
        forward(pid_spd);
        get_AngleZ();
        controlPIDAngle(imu_overall_val);
      }
    }
    revultra();
  }
  if (dist(6, 3) <= 100 && dist(6, 3) > 0) {
    forward(pid_spd_slow);
    get_AngleZ();
    controlPIDAngle(imu_overall_val);
    if (dist(arr2[2], 3) > 90 || dist(arr2[0], 3) > 90) {
      stopp();
      turn();
    }
  }
  if (dist(6, 3) > 100) {
    forward(pid_spd);
    get_AngleZ();
    controlPIDAngle(imu_overall_val);
  }

  if (counter == 12) {
    stopp();
    delay(1000000);
  }
}
